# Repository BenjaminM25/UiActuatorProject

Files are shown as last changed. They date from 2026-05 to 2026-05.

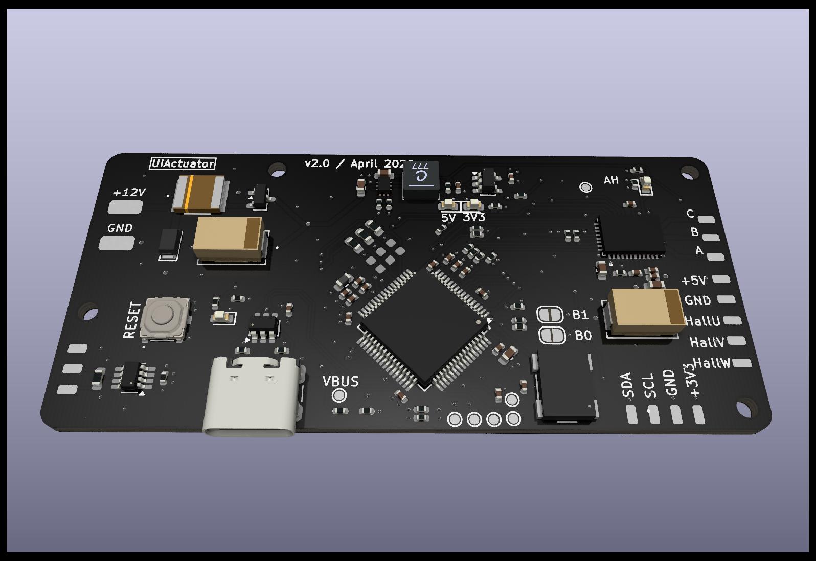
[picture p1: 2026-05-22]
KiCad/PCB_Layout/PCB_raytr.jpg

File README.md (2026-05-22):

# Closed-Loop Linear Actuator

> Bachelor project, University of Agder (UiA), 2026
> Custom BLDC motor controller for a leadscrew linear actuator with
> closed-loop position control.

## Overview

This project contains code and production files for a small linear
actuator using the lead screw principle with a custom pcb. The system
consists of a 12 mm BLDC motor with a 1:24 gearbox, integrated hall-
sensors for motor commutation, a AS5600L magnetic encoder module for
position/velocity control. It also supports communication over CAN
and USB-C.

A demonstration video of the actuator can be found here:

[Demonstration video](https://youtube.com/watch?v=XubzCKECgCM)

## Features

- Trapezoidal 3-PWM/6-PWM commutation (Hall-sensor based)
- Closed-loop position control (profiled trajectory + PID)
- Phase current sensing via ADC
- On-chip temperature monitoring with thermal protection
- CAN (FDCAN) communication
- Live telemetry over USB CDC (Teleplotter)

## Hardware

| Component | Part |
|---|---|
| MCU | STM32G473RC |
| Gate driver | DRV8316 (SPI) |
| Position encoder | AS5600L (I2C) |
| Commutation | Hall sensors |
| CAN transceiver  | TCAN3403 |
| Motor | 12 mm BLDC, 1:24 |

## Third Party

The DRV8316 BLDC Driver has been adapted from the[SIMPLEFOC](https://github.com/simplefoc/Arduino-FOC-drivers/tree/master/src/drivers/drv8316) GitHub library.

## Building & flashing

The CubeIDE project contains custom files for the actuator
within Core/Actuator. The DRV8316 driver, hall encoder and
magnetic encoder is found in Drivers/DRV8316.

The .elf file generated in Debug after building the project
is uploaded to the pcb using STM32CubeProgrammer. First time use
of the pcb requires either a ST-Link debugger using swd or
programming USB-C by setting the mcu in the
DFU(device firmware upgrade) mode.

## Disclaimer

Portions of this firmware were developed with the assistance of
AI-generated code. All such content has been reviewed, tested, and
adapted by the author.

## License
This project is licensed under the MIT License — see the [LICENSE](LICENSE) file.

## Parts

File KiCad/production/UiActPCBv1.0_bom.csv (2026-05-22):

Designator | Footprint | Quantity | Value | LCSC Part #
C1, C14, C15, C22, C24 | C_0402 | 5 | 1uF | C14445
C10, C8, C9 | C_0402 | 3 | 30pF | C107004
C11, C13 | 0603 | 2 | 22uF | C29519229
C12 | 0603 | 1 | 10uF | C96446
C16 | 0603 | 1 | 10uF | C19702
C17, C18, C19, C20, C21, C23, C25, C26 | C_0402 | 8 | 0.1uF | C71687
C2 | 0603 | 1 | 10 uF | C96446
C27 | CAP_EEF_CX_PAN | 1 | EEF-CX0D221R | C165968
C3 | C_0402 | 1 | 0.1 uF | C56392
C31, C32, C33 | C_0402 | 3 | 100nF | C71687
C4 | C_0402 | 1 | 1 uF | C52923
C5, C7 | C_0402 | 2 | 0.1 uF | C71687
C6 | C_0402 | 1 | 47 nF | C285062
D1, D2, D4 | 0603 | 3 | green | C12624
D3 | 0603 | 1 | red | C2286
D5 | VS12VBA1HST15R | 1 | VS12VBA1HST15R | C3711499
F1 | FUSE_SMDF050-2 | 1 | Fuse | C135370
FB1 | L_0603 | 1 | 330R | C113010
J21 | USB_C_Receptacle_GCT_USB4105-xx-A_16P_TopMnt_Horizontal | 1 | USB_C_Receptacle_USB2.0_14P | C2927038
L1 | L_Coilcraft_XxL4020 | 1 | 1u | C5357696
Q1 | SOT-23 | 1 | NCE3407 | C113770
R1, R28, R29 | R_0402 | 3 | 5.1k | C25905
R10, R7, R9 | R_0402 | 3 | 100k | C25530
R11 | R_0402 | 1 | 200k | C25764
R12 | R_0402 | 1 | 470 | C25117
R13, R16 | R_0402 | 2 | 100 | C25076
R14 | R_0402 | 1 | 76.8k | C26987
R15 | R_0402 | 1 | 520 | C25123
R17, R18, R19, R20 | R_0402 | 4 | 10k | C60489
R2, R3, R4 | R_0402 | 3 | 1000 Ohm | C11702
R24 | R_0603 | 1 | 120 | C25079
R25, R26 | R_0402 | 2 | 40k | C25783
R27 | R_0402 | 1 | 33k | C25779
R30 | R_0402 | 1 | 82k | C4142
R5 | R_0402 | 1 | 22 | C25092
R6, R8 | R_0402 | 2 | 10k | C25531
S1 | EVQPLHA15_pushbutton | 1 | EVQ-PLHA15 | C79172
U1 | RGF0040E-IPC_A | 1 | DRV8316RQRGFRQ1 | C5218859
U2 | TPS62903RPJRRPJ0009A | 1 | TPS62903RPJR | C2866502
U3 | SOT-23-5 | 1 | AP2112K-3.3 | C51118
U4 | LQFP-64_10x10mm_P0.5mm | 1 | STM32G473RCTx | C529361
U5 | SOT-23-8_Handsoldering | 1 | TCAN3403 | C35926232
U6 | SOT-23-6 | 1 | USBLC6-2SC6 | C7519
Y1 | X1G004481009712_EPS | 1 | SG-7050CAN | C70513

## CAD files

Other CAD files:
CAD_files/Actuator/Enclosure_assembly.SLDASM
CAD_files/Actuator/SquareTube_bushing.SLDASM
CAD_files/Actuator/AluminiumPipe_magnetball.SLDASM
CAD_files/Actuator/Gear_motor_assembly.SLDASM
CAD_files/Actuator/Motor_with_components.SLDASM
CAD_files/Actuator/Actuator_assembly.SLDASM
KiCad/3D_models/S3B-XH-SM4-TB-LF--SN---3DModel-STEP-56544.STEP
KiCad/Custom_ESC.step
CAD_files/Actuator/AluminiumPipe.SLDPRT
KiCad/3D_models/X1G004481009712_EPS.step
CAD_files/Actuator/MagnetEncoder.SLDPRT
KiCad/3D_models/GX_SX_CX_HX.stp
CAD_files/Actuator/M2HeatInsert.SLDPRT
KiCad/3D_models/XFL4020-102MEC.stp
KiCad/3D_models/SMASeries_LTF.step
KiCad/3D_models/TYPE-C-31-M-12--3DModel-STEP-56544.STEP
CAD_files/Actuator/Enclosure.SLDPRT
CAD_files/Actuator/M2_PanHead.SLDPRT
CAD_files/Actuator/BLDC_motor.SLDPRT
CAD_files/Actuator/BallBearing.SLDPRT
CAD_files/Actuator/Enclosure_PCB.SLDPRT
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

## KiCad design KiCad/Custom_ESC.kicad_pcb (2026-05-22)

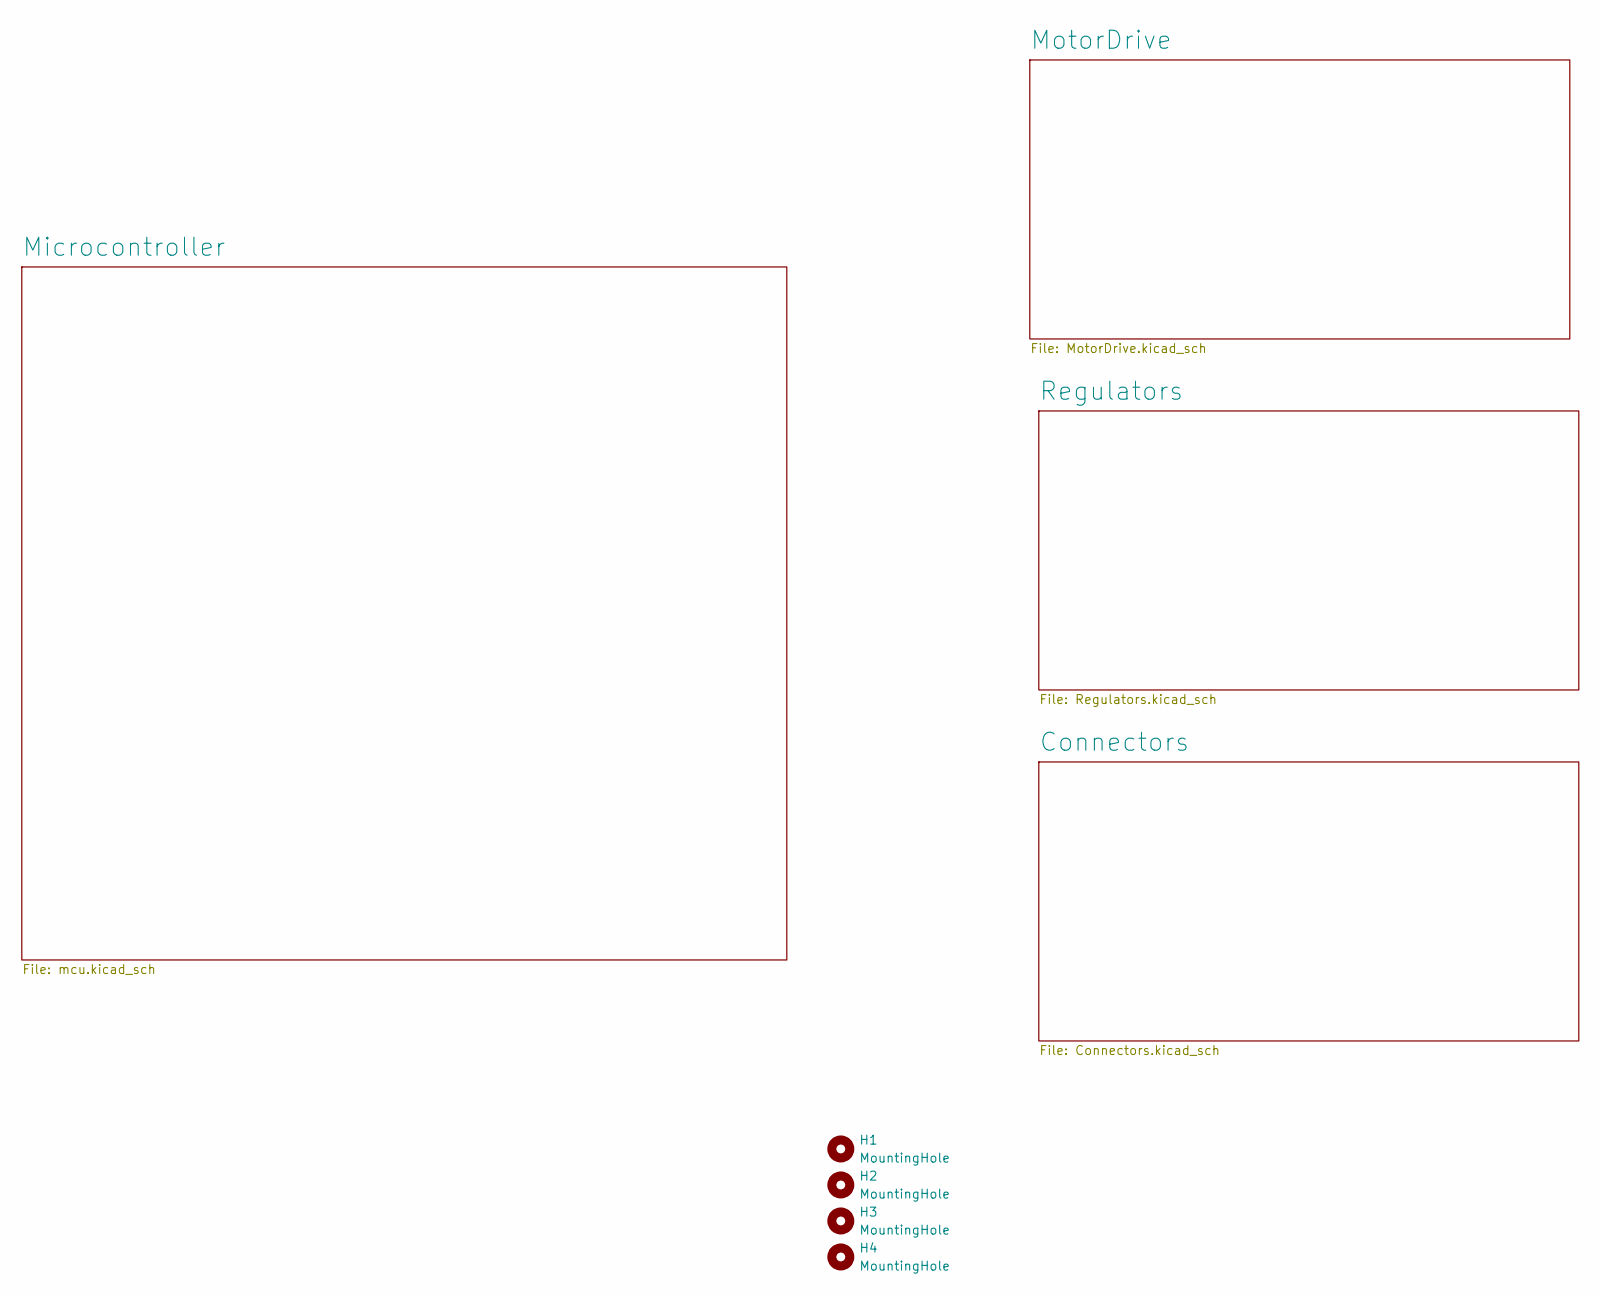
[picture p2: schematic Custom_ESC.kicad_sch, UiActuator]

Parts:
H1, H2, H3, H4: MountingHole; MountingHole_2.2mm_M2

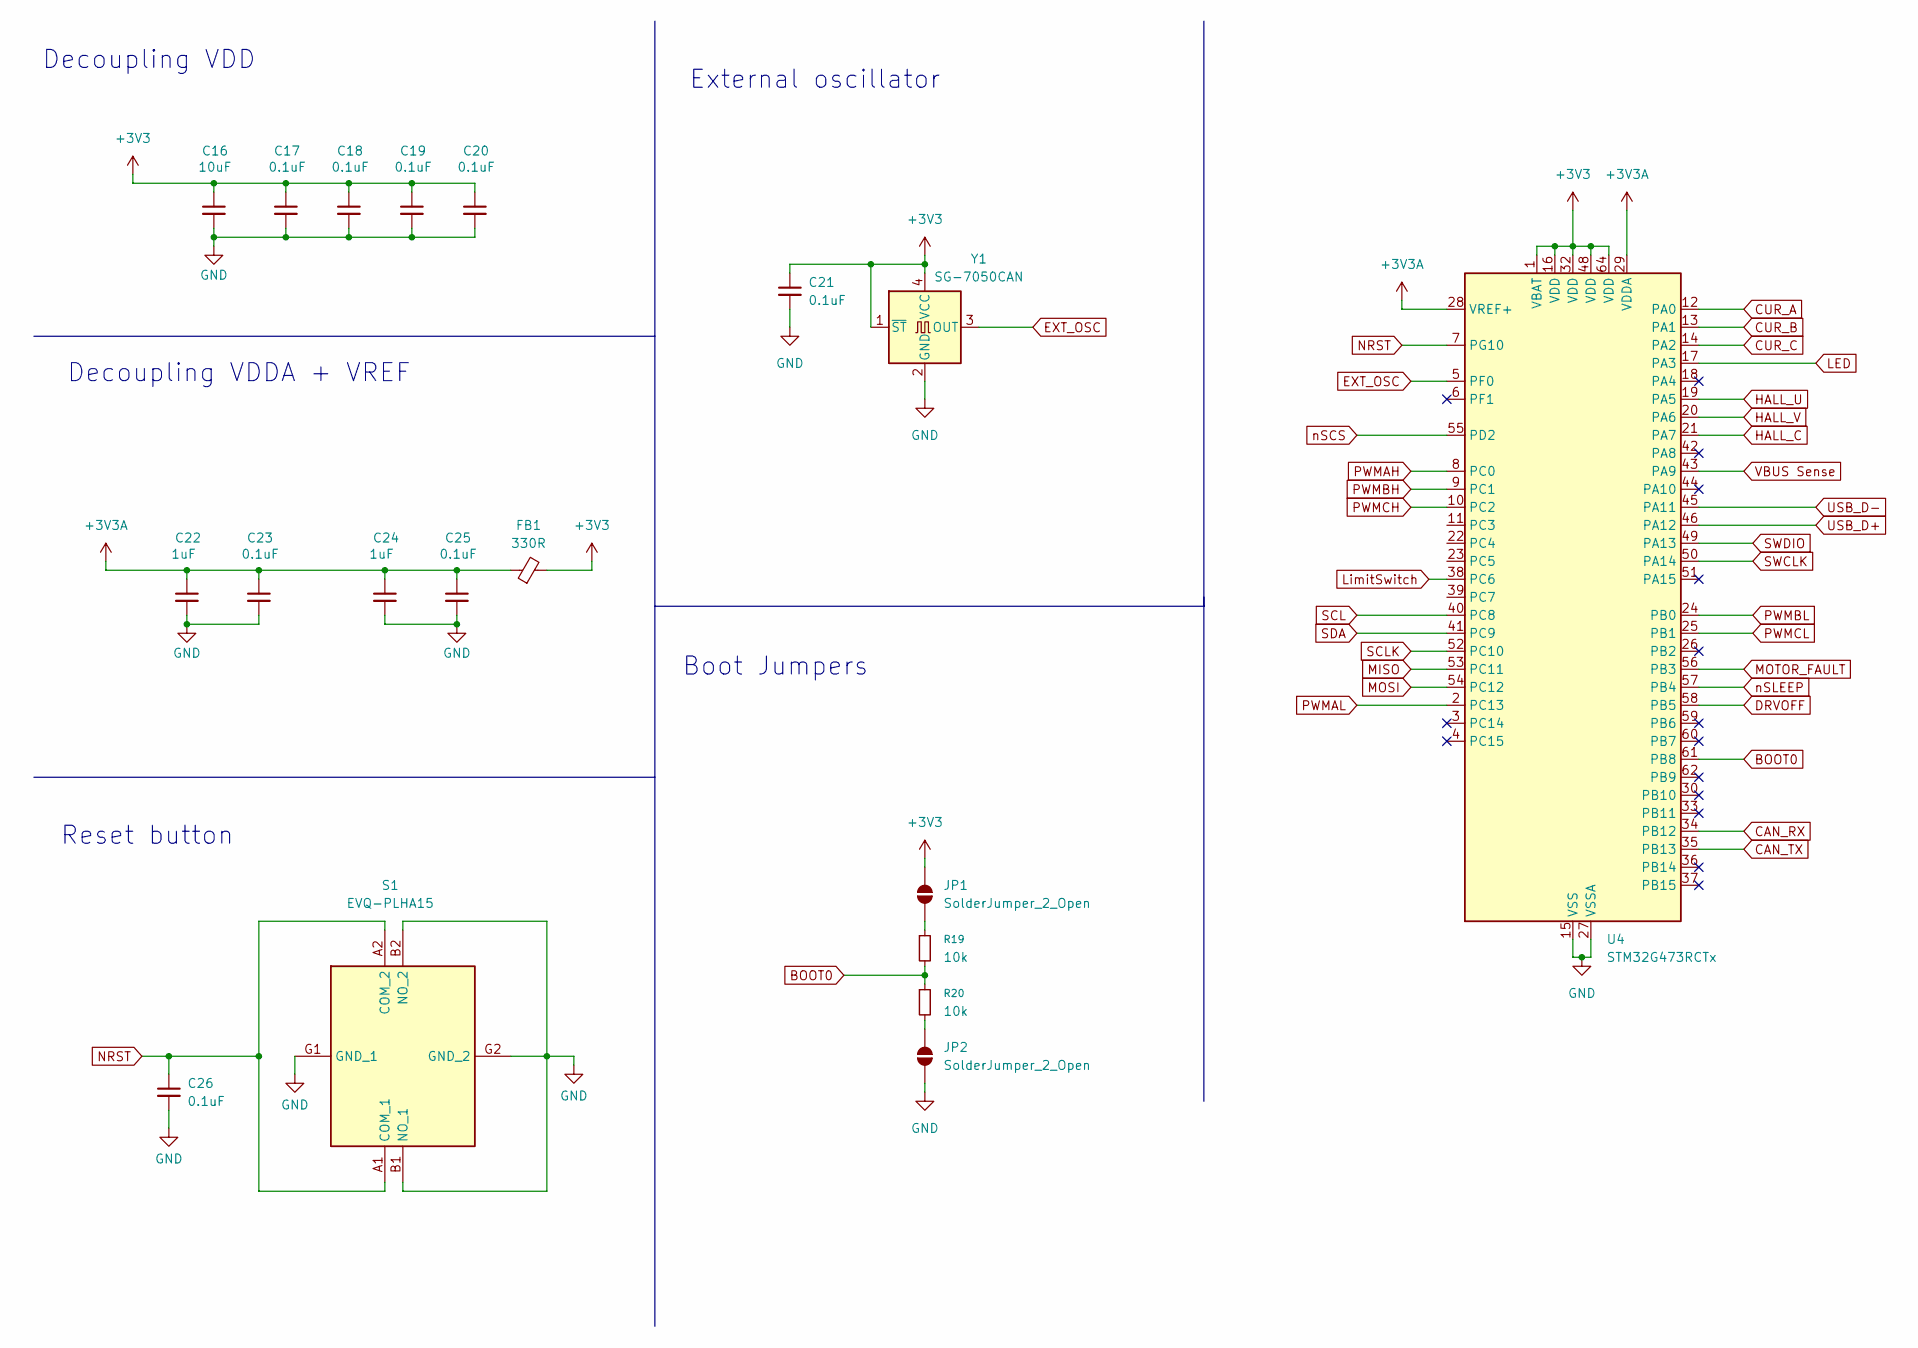
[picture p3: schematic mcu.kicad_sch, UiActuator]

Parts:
C16: 10uF; C_0603_1608Metric; LCSC C19702
C17, C18, C19, C20, C21, C23, C25, C26: 0.1uF; C_0402; LCSC C71687
C22, C24: 1uF; C_0402; LCSC C14445
FB1: 330R; L_0603; LCSC C113010
JP1, JP2: SolderJumper_2_Open; SolderJumper-2_P1.3mm_Open_RoundedPad1.0x1.5mm
R19, R20: 10k; R_0402; LCSC C60489
S1: EVQ-PLHA15; EVQPLHA15_pushbutton; Mouser Part Number 667-EVQ-PLHA15
U4: STM32G473RCTx; LQFP-64_10x10mm_P0.5mm; LCSC C529361
Y1: SG-7050CAN; X1G004481009712_EPS; LCSC C70513

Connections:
+3V3: C16.1, C17.1, C18.1, C19.1, C20.1, C21.1, FB1.2, JP1.2 (B), U4.1 (VBAT), U4.16 (VDD), U4.32 (VDD), U4.48 (VDD), U4.64 (VDD), Y1.1 (~ST), Y1.4 (VCC); also elsewhere on the board
+3V3A: C22.1, C23.1, C24.1, C25.1, FB1.1, U4.28 (VREF+), U4.29 (VDDA); also elsewhere on the board
BOOT0: R19.2, R20.1, U4.61 (PB8)
CAN_RX: U4.34 (PB12); also elsewhere on the board
CAN_TX: U4.35 (PB13); also elsewhere on the board
CUR_A: U4.12 (PA0); also elsewhere on the board
CUR_B: U4.13 (PA1); also elsewhere on the board
CUR_C: U4.14 (PA2); also elsewhere on the board
DRVOFF: U4.58 (PB5); also elsewhere on the board
EXT_OSC: U4.5 (PF0), Y1.3 (OUT)
GND: C16.2, C17.2, C18.2, C19.2, C20.2, C21.2, C22.2, C23.2, C24.2, C25.2, C26.2, JP2.1 (A), S1.B1 (NO_1), S1.B2 (NO_2), S1.G1 (GND_1), S1.G2 (GND_2), U4.15 (VSS), U4.27 (VSSA), U4.31 (VSS), U4.47 (VSS), U4.63 (VSS), Y1.2 (GND); also elsewhere on the board
HALL_C: U4.21 (PA7); also elsewhere on the board
HALL_U: U4.19 (PA5); also elsewhere on the board
HALL_V: U4.20 (PA6); also elsewhere on the board
LED: U4.17 (PA3); also elsewhere on the board
LimitSwitch: U4.38 (PC6); also elsewhere on the board
MISO: U4.53 (PC11); also elsewhere on the board
MOSI: U4.54 (PC12); also elsewhere on the board
MOTOR_FAULT: U4.56 (PB3); also elsewhere on the board
NRST: C26.1, S1.A1 (COM_1), S1.A2 (COM_2), U4.7 (PG10); also elsewhere on the board
unnamed: JP1.1 (A), R19.1
unnamed: JP2.2 (B), R20.2
PWMAH: U4.8 (PC0); also elsewhere on the board
PWMAL: U4.2 (PC13); also elsewhere on the board
PWMBH: U4.9 (PC1); also elsewhere on the board
PWMBL: U4.24 (PB0); also elsewhere on the board
PWMCH: U4.10 (PC2); also elsewhere on the board
PWMCL: U4.25 (PB1); also elsewhere on the board
SCL: U4.40 (PC8); also elsewhere on the board
SCLK: U4.52 (PC10); also elsewhere on the board
SDA: U4.41 (PC9); also elsewhere on the board
SWCLK: U4.50 (PA14); also elsewhere on the board
SWDIO: U4.49 (PA13); also elsewhere on the board
USB_D+: U4.46 (PA12); also elsewhere on the board
USB_D-: U4.45 (PA11); also elsewhere on the board
VBUS Sense: U4.43 (PA9); also elsewhere on the board
nSCS: U4.55 (PD2); also elsewhere on the board
nSLEEP: U4.57 (PB4); also elsewhere on the board

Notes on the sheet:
External oscillator
Decoupling VDD
Reset button
Boot Jumpers
Decoupling VDDA + VREF

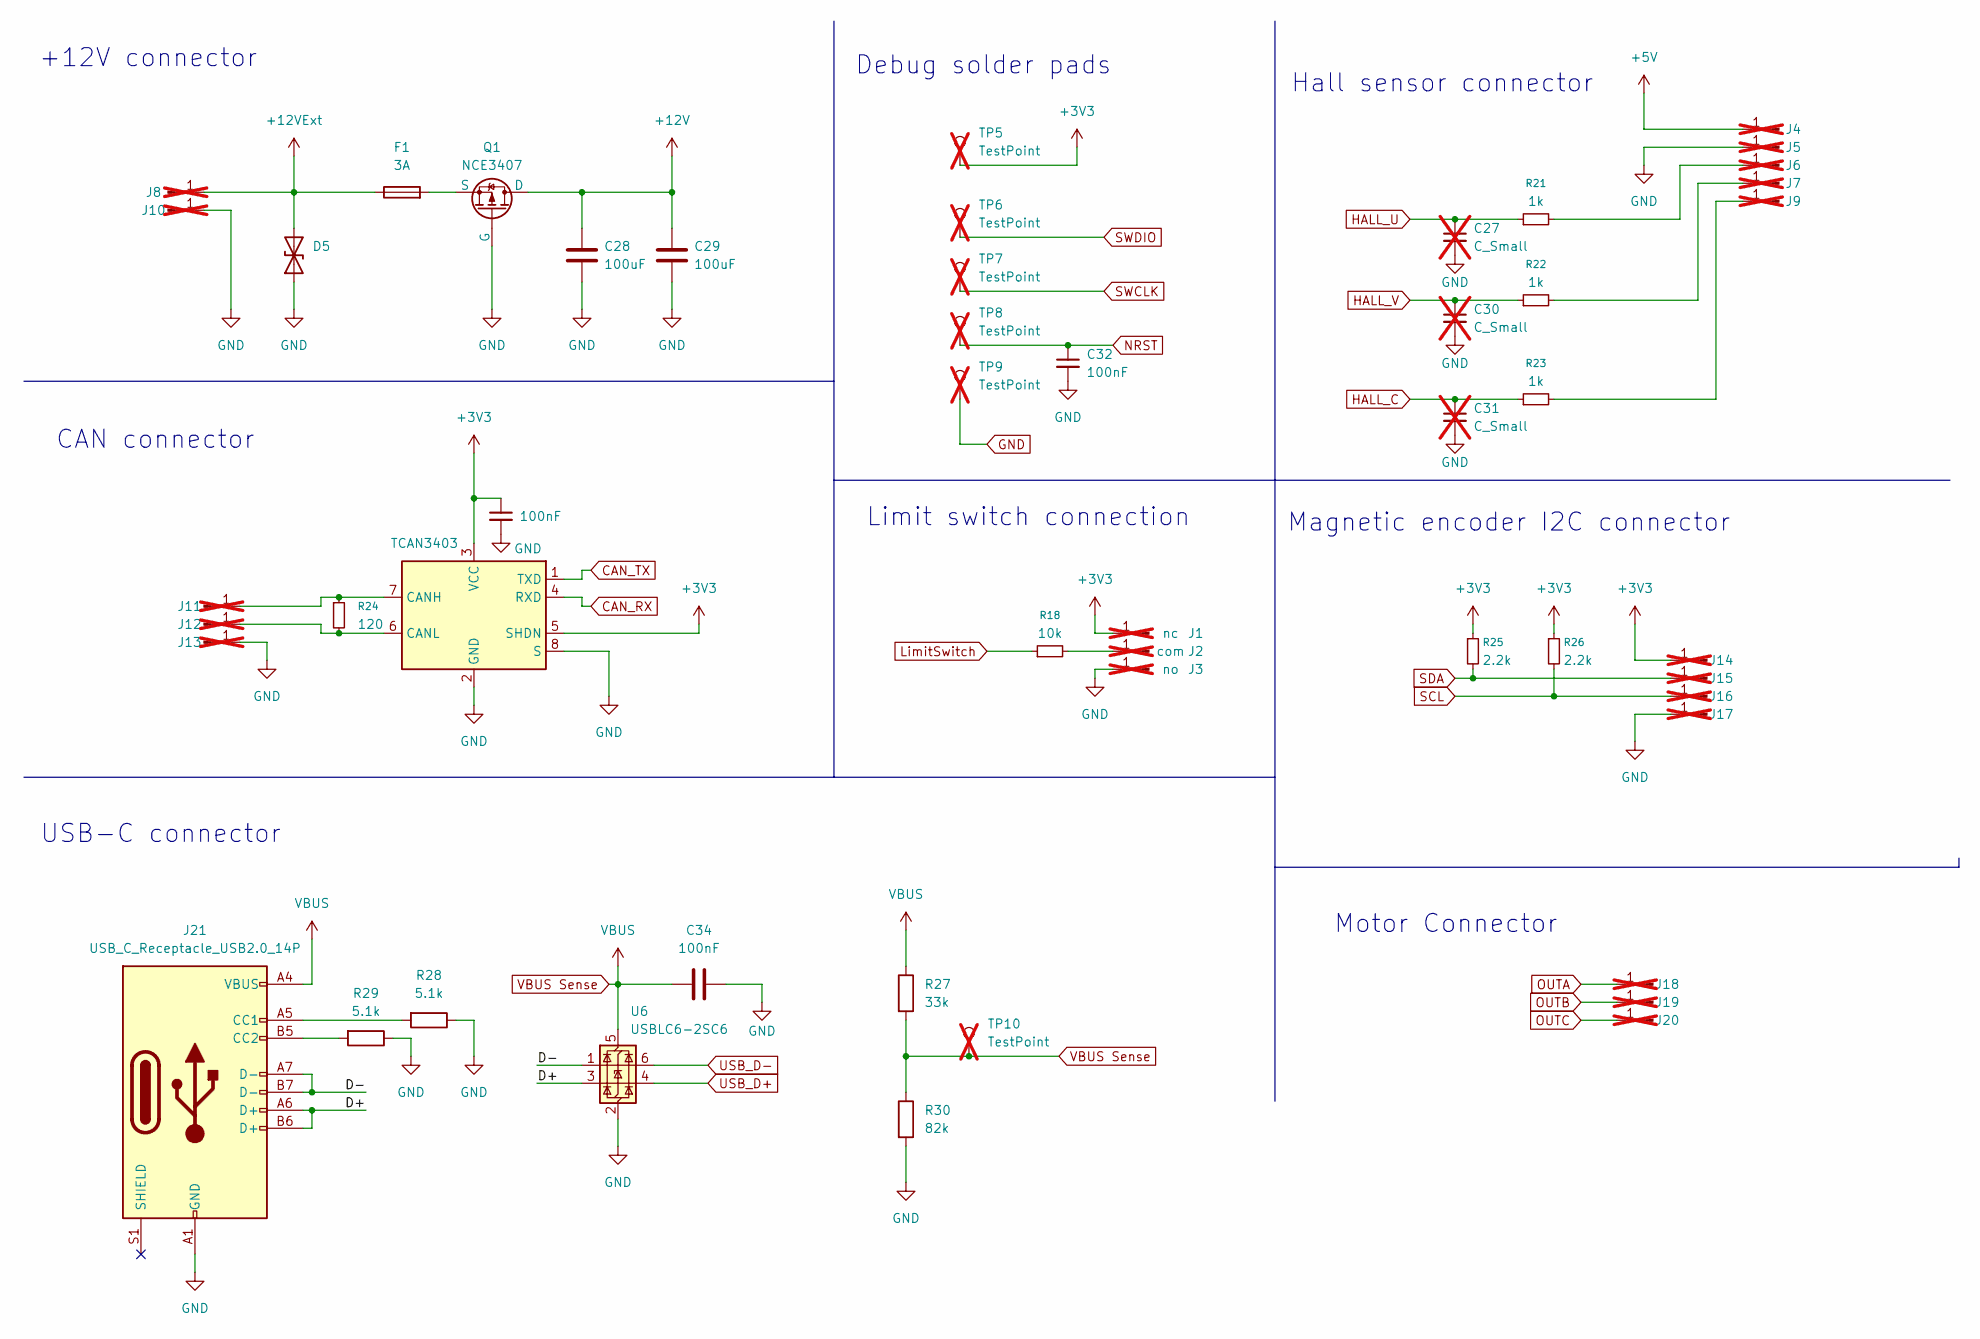
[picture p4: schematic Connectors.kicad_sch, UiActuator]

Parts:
C27, C30, C31: C_Small; C_0603; not fitted
C28, C29: 100uF; CAP_T55D_VIS; LCSC C215892
C32, C33, C34: 100nF; C_0402; LCSC C71687
D5: 13; D_SOD-123FL; LCSC C5353308
F1: 3A; FUSE_SMDF050-2; LCSC C135370
J1: nc; TestPoint_Pad_D1.0mm; not fitted
J2: com; TestPoint_Pad_D1.0mm; not fitted
J3: no; TestPoint_Pad_D1.0mm; not fitted
J4, J5, J6, J7, J9, J11, J12, J13, J14, J15, J16, J17, J18, J19, J20: A; SolderWirePad_1x01_SMD_1x2mm; not fitted
J8, J10: A; SolderWirePad_1x01_SMD_2x4mm; not fitted
J21: USB_C_Receptacle_USB2.0_14P; USB_C_Receptacle_GCT_USB4105-xx-A_16P_TopMnt_Horizontal; LCSC C2927038
Q1: NCE3407; SOT-23; LCSC C113770
R18: 10k; R_0402; LCSC C60489
R21, R22, R23: 1k; C_0603; LCSC C21190
R24: 120; R_0603; LCSC C22787
R25, R26: 2.2k; R_0402; LCSC C25879
R27: 33k; R_0402; LCSC C25779
R28, R29: 5.1k; R_0402; LCSC C25905
R30: 82k; R_0402; LCSC C4142
TP5, TP6, TP7, TP8, TP9, TP10: TestPoint; TestPoint_Pad_D1.0mm; not fitted
U5: TCAN3403; SOT-23-8_Handsoldering; LCSC C35926232
U6: USBLC6-2SC6; SOT-23-6; LCSC C7519

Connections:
+3V3: C33.1, J1.1, J14.1, R25.1, R26.1, TP5.1, U5.3 (VCC), U5.5 (SHDN); also elsewhere on the board
+5V: J4.1; also elsewhere on the board
+12V: C28.1, C29.1, Q1.3 (D); also elsewhere on the board
+12VExt: D5.2 (A2), F1.1, J8.1
/Connectors/D+: J21.A6 (D+), J21.B6 (D+), U6.3 (I/O2)
/Connectors/D-: J21.A7 (D-), J21.B7 (D-), U6.1 (I/O1)
CAN_RX: U5.4 (RXD); also elsewhere on the board
CAN_TX: U5.1 (TXD); also elsewhere on the board
GND: C27.2, C28.2, C29.2, C30.2, C31.2, C32.2, C33.2, C34.1, D5.1 (A1), J3.1, J5.1, J10.1, J13.1, J17.1, J21.A1 (GND), J21.A12 (GND), J21.B1 (GND), J21.B12 (GND), Q1.1 (G), R28.1, R29.1, R30.2, TP9.1, U5.2 (GND), U5.8 (S), U6.2 (GND); also elsewhere on the board
HALL_C: C31.1, R23.1; also elsewhere on the board
HALL_U: C27.1, R21.1; also elsewhere on the board
HALL_V: C30.1, R22.1; also elsewhere on the board
LimitSwitch: R18.1; also elsewhere on the board
NRST: C32.1, TP8.1; also elsewhere on the board
unnamed: J2.1, R18.2
unnamed: J6.1, R21.2
unnamed: J7.1, R22.2
unnamed: J9.1, R23.2
unnamed: J11.1, R24.1, U5.7 (CANH)
unnamed: J12.1, R24.2, U5.6 (CANL)
unnamed: J21.A5 (CC1), R28.2
unnamed: J21.B5 (CC2), R29.2
unnamed: F1.2, Q1.2 (S)
OUTA: J18.1; also elsewhere on the board
OUTB: J19.1; also elsewhere on the board
OUTC: J20.1; also elsewhere on the board
SCL: J16.1, R26.2; also elsewhere on the board
SDA: J15.1, R25.2; also elsewhere on the board
SWCLK: TP7.1; also elsewhere on the board
SWDIO: TP6.1; also elsewhere on the board
USB_D+: U6.4 (I/O2); also elsewhere on the board
USB_D-: U6.6 (I/O1); also elsewhere on the board
VBUS Sense: C34.2, J21.A4 (VBUS), J21.A9 (VBUS), J21.B4 (VBUS), J21.B9 (VBUS), R27.1, R27.2, R30.1, TP10.1, U6.5 (VBUS); also elsewhere on the board

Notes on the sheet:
USB-C connector
Hall sensor connector
CAN connector
Magnetic encoder I2C connector
Motor Connector
+12V connector
Limit switch connection
Debug solder pads

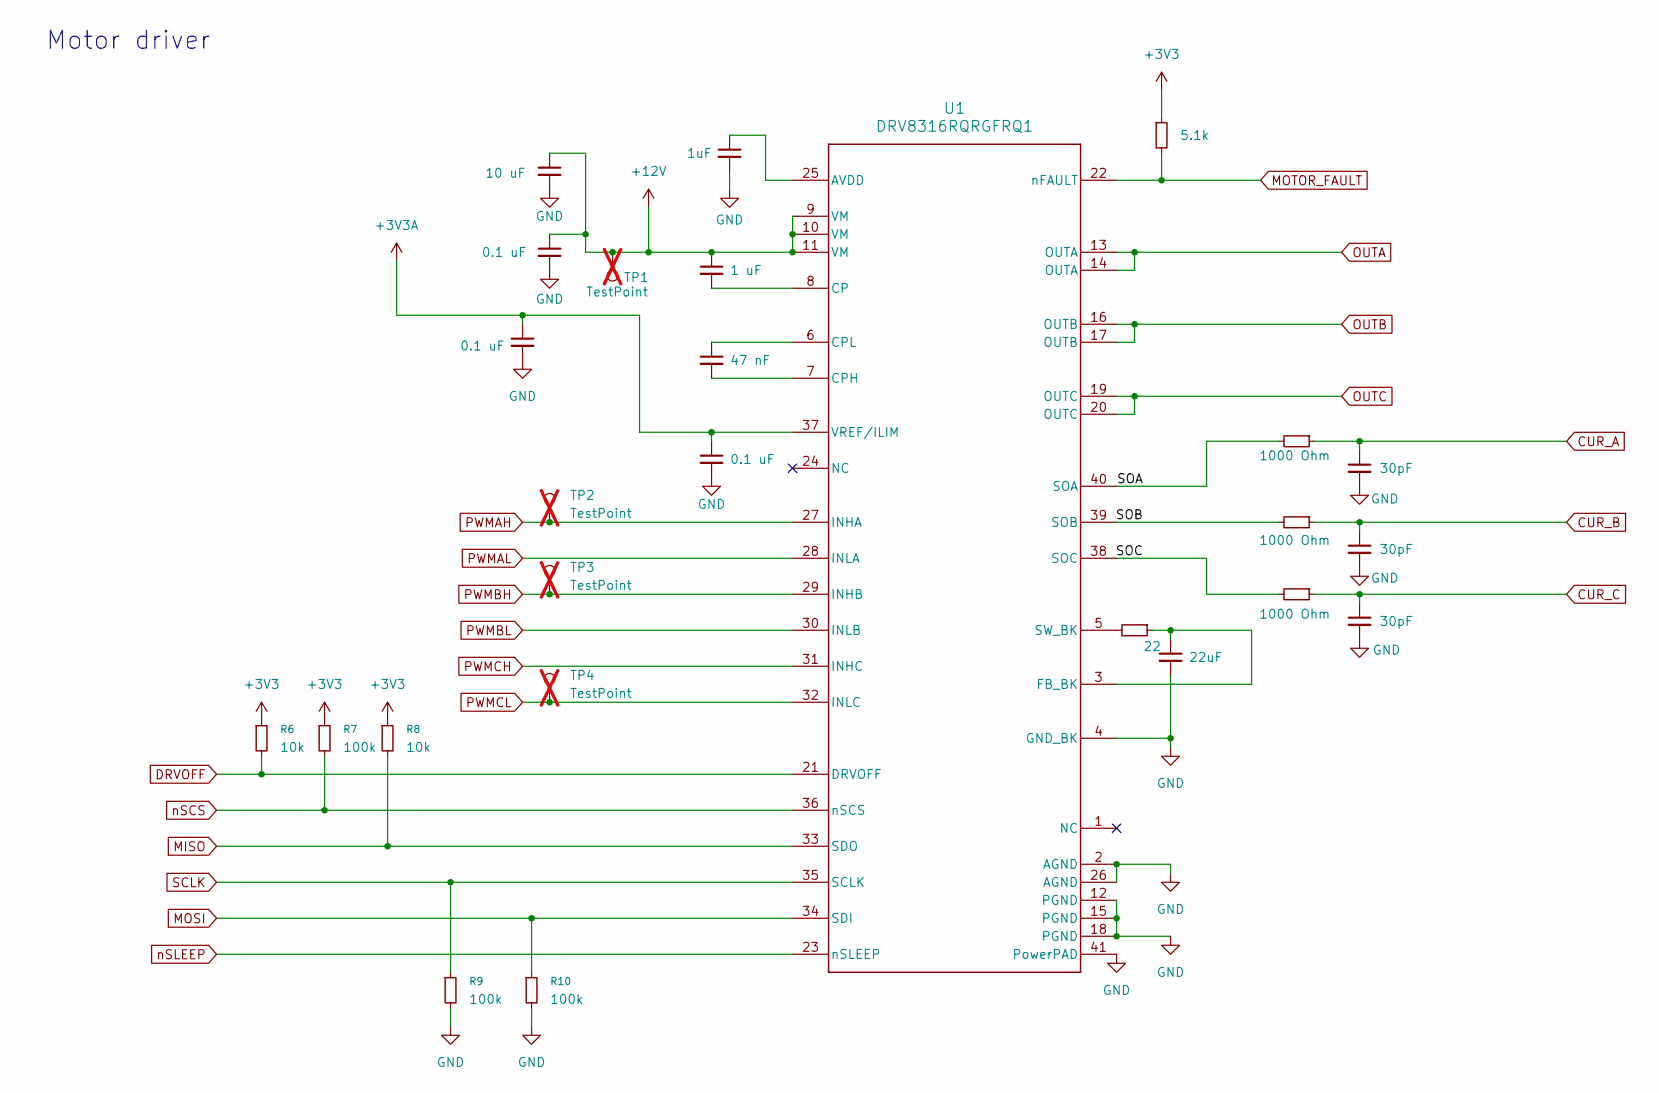
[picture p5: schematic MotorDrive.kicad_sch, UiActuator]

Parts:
C1: 1uF; C_0402; LCSC C14445
C2: 10 uF; C_0603_1608Metric; LCSC C96446
C3: 0.1 uF; C_0402; LCSC C56392
C4: 1 uF; C_0402; LCSC C52923
C5, C7: 0.1 uF; C_0402; LCSC C71687
C6: 47 nF; C_0402; LCSC C285062
C8, C9, C10: 30pF; C_0402; LCSC C107004
C11: 22uF; C_0603_1608Metric; LCSC C29519229
R1: 5.1k; R_0402; LCSC C25905
R2, R3, R4: 1000 Ohm; R_0402; LCSC C11702
R5: 22; R_0402; LCSC C25092
R6, R8: 10k; R_0402; LCSC C25531
R7, R9, R10: 100k; R_0402; LCSC C25530
TP1, TP2, TP3, TP4: TestPoint; TestPoint_Pad_D1.0mm; not fitted
U1: DRV8316RQRGFRQ1; RGF0040E-IPC_A; LCSC C5218859

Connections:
+3V3: R1.1, R6.1, R7.1, R8.1; also elsewhere on the board
+3V3A: C5.1, C7.1, U1.37 (VREF/ILIM); also elsewhere on the board
+12V: C2.1, C3.1, C4.1, TP1.1, U1.9 (VM), U1.10 (VM), U1.11 (VM); also elsewhere on the board
/MotorDrive/SOA: R2.2, U1.40 (SOA)
/MotorDrive/SOB: R3.2, U1.39 (SOB)
/MotorDrive/SOC: R4.2, U1.38 (SOC)
CUR_A: C8.1, R2.1; also elsewhere on the board
CUR_B: C9.1, R3.1; also elsewhere on the board
CUR_C: C10.1, R4.1; also elsewhere on the board
DRVOFF: R6.2, U1.21 (DRVOFF); also elsewhere on the board
GND: C1.2, C2.2, C3.2, C5.2, C7.2, C8.2, C9.2, C10.2, C11.2, R9.2, R10.2, U1.2 (AGND), U1.4 (GND_BK), U1.12 (PGND), U1.15 (PGND), U1.18 (PGND), U1.26 (AGND), U1.41 (PowerPAD); also elsewhere on the board
MISO: R8.2, U1.33 (SDO); also elsewhere on the board
MOSI: R10.1, U1.34 (SDI); also elsewhere on the board
MOTOR_FAULT: R1.2, U1.22 (nFAULT); also elsewhere on the board
unnamed: C1.1, U1.25 (AVDD)
unnamed: C4.2, U1.8 (CP)
unnamed: C6.2, U1.7 (CPH)
unnamed: C6.1, U1.6 (CPL)
unnamed: C11.1, R5.1, U1.3 (FB_BK)
unnamed: R5.2, U1.5 (SW_BK)
OUTA: U1.13 (OUTA), U1.14 (OUTA); also elsewhere on the board
OUTB: U1.16 (OUTB), U1.17 (OUTB); also elsewhere on the board
OUTC: U1.19 (OUTC), U1.20 (OUTC); also elsewhere on the board
PWMAH: TP2.1, U1.27 (INHA); also elsewhere on the board
PWMAL: U1.28 (INLA); also elsewhere on the board
PWMBH: TP3.1, U1.29 (INHB); also elsewhere on the board
PWMBL: U1.30 (INLB); also elsewhere on the board
PWMCH: U1.31 (INHC); also elsewhere on the board
PWMCL: TP4.1, U1.32 (INLC); also elsewhere on the board
SCLK: R9.1, U1.35 (SCLK); also elsewhere on the board
nSCS: R7.2, U1.36 (nSCS); also elsewhere on the board
nSLEEP: U1.23 (nSLEEP); also elsewhere on the board

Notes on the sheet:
Motor driver

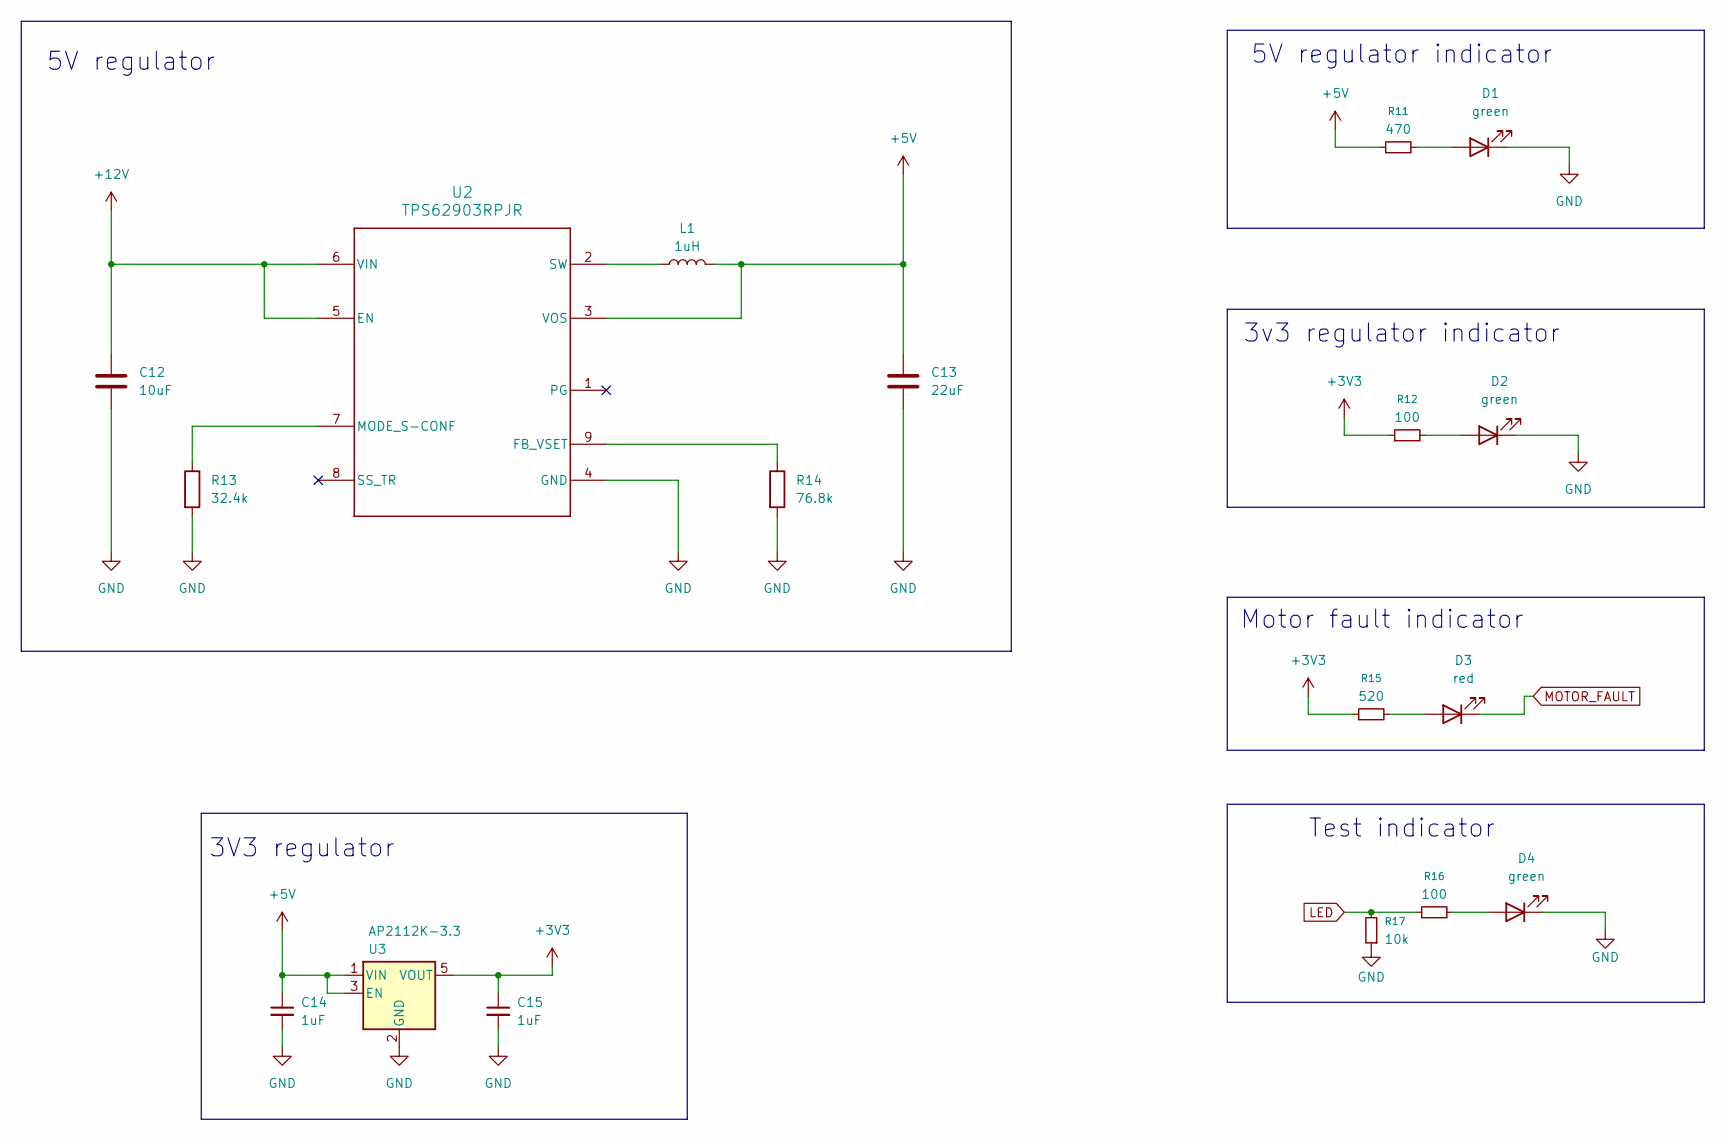
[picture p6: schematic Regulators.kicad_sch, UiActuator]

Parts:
C12: 10uF; C_0603_1608Metric; LCSC C96446
C13: 22uF; C_0603_1608Metric; LCSC C29519229
C14, C15: 1uF; C_0402; LCSC C14445
D1, D2, D4: green; LED_0603_1608Metric; LCSC C12624
D3: red; LED_0603_1608Metric; LCSC C2286
L1: 1uH; L_Coilcraft_XxL4020; LCSC C5357696
R11: 470; R_0402; LCSC C25117
R12, R16: 100; R_0402; LCSC C25076
R13: 32.4k; R_0402; LCSC C26974
R14: 76.8k; R_0402; LCSC C26987
R15: 520; R_0402; LCSC C25123
R17: 10k; R_0402; LCSC C60489
U2: TPS62903RPJR; TPS62903RPJRRPJ0009A; LCSC C2866502
U3: AP2112K-3.3; SOT-23-5; LCSC C51118

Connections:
+3V3: C15.1, R12.1, R15.1, U3.5 (VOUT); also elsewhere on the board
+5V: C13.1, C14.1, L1.2, R11.1, U2.3 (VOS), U3.1 (VIN), U3.3 (EN); also elsewhere on the board
+12V: C12.1, U2.5 (EN), U2.6 (VIN); also elsewhere on the board
GND: C12.2, C13.2, C14.2, C15.2, D1.1 (K), D2.1 (K), D4.1 (K), R13.2, R14.2, R17.1, U2.4 (GND), U3.2 (GND); also elsewhere on the board
LED: R16.1, R17.2; also elsewhere on the board
MOTOR_FAULT: D3.1 (K); also elsewhere on the board
unnamed: D1.2 (A), R11.2
unnamed: D2.2 (A), R12.2
unnamed: D3.2 (A), R15.2
unnamed: D4.2 (A), R16.2
unnamed: R14.1, U2.9 (FB_VSET)
unnamed: R13.1, U2.7 (MODE_S-CONF)
unnamed: L1.1, U2.2 (SW)

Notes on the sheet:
3v3 regulator indicator
Motor fault indicator
5V regulator
3V3 regulator
Test indicator
5V regulator indicator

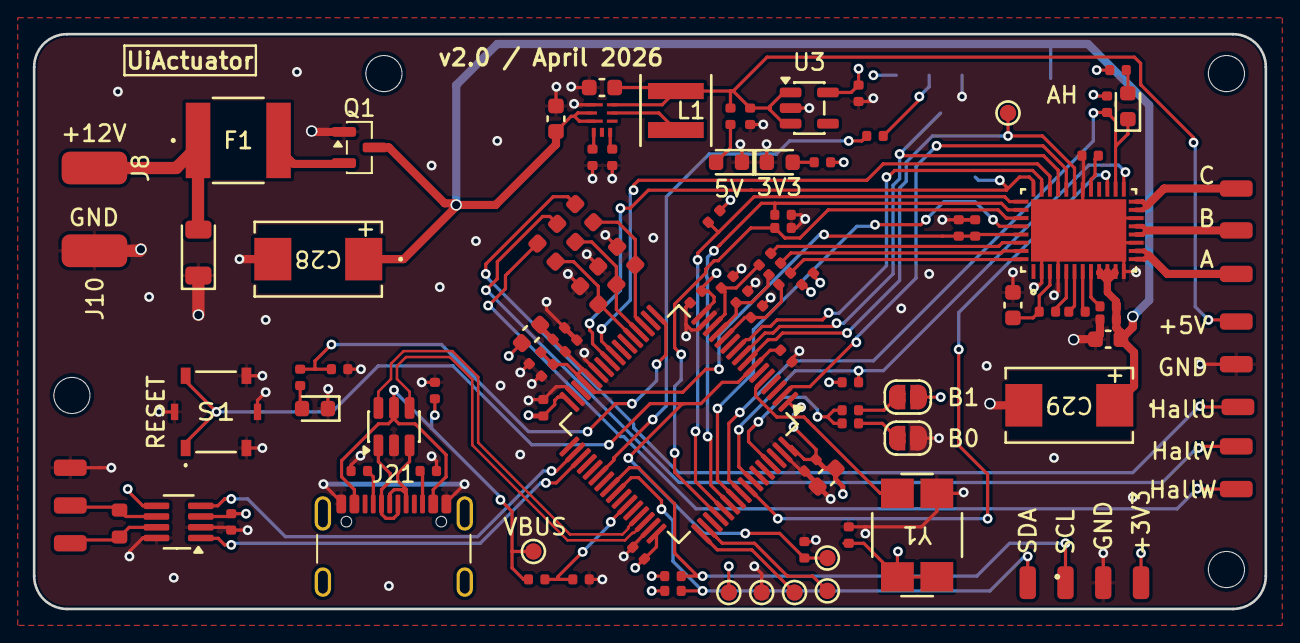
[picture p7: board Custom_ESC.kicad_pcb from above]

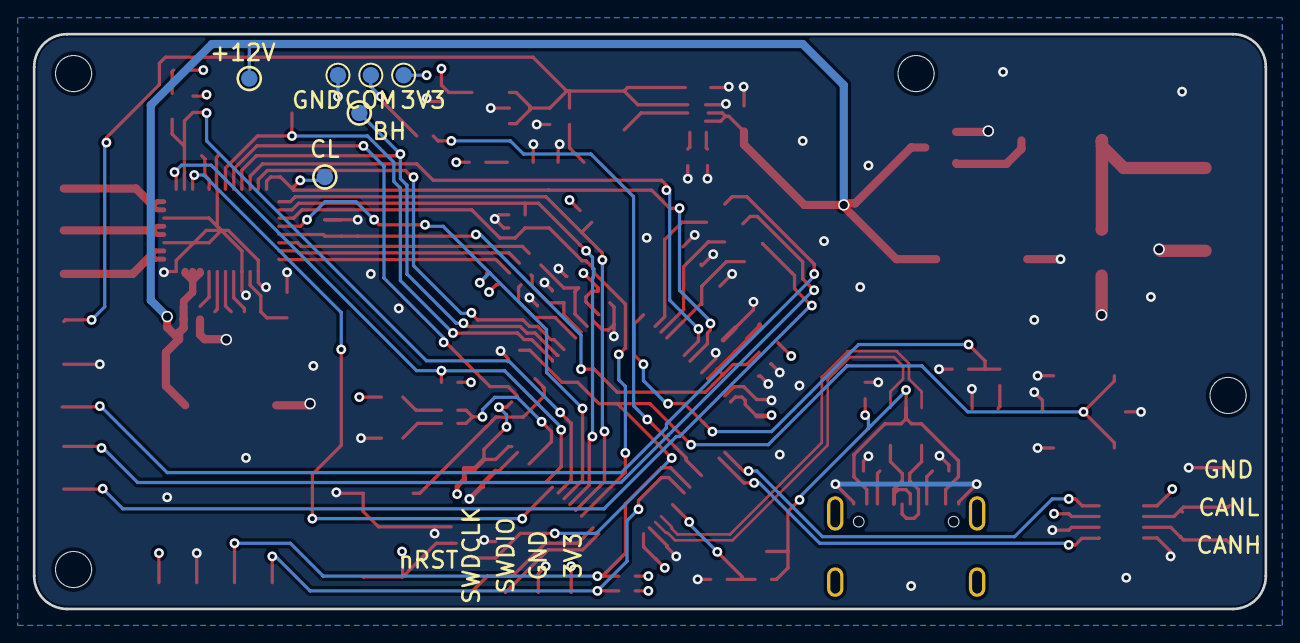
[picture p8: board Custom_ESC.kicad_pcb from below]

Board: 4 copper layers, 75.0 x 35.0 mm, 118 parts (6 on the bottom side), 71 nets.

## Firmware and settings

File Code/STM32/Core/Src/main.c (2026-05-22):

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
/* Includes ------------------------------------------------------------------*/
#include "main.h"
#include "adc.h"
#include "fdcan.h"
#include "i2c.h"
#include "spi.h"
#include "tim.h"
#include "usb_device.h"
#include "gpio.h"

/* USER CODE BEGIN Includes */

#include "bootloader.h"
#include "TestUSB.h"
#include "testcan.h"
#include "testhall.h"
#include "MotorApp.h"
#include "SPITest.h"
#include "Diagnostics.h"
#include "plot.h"
#include "Commcalib.h"
#include "TestADC.h"
#include "TempSensor.h"
#include "TempTest.h"
#include "CANBus.h"

/* USER CODE END Includes */


/* USER CODE BEGIN PV */

  uint32_t last_encoder = 0;
  uint32_t last_usb     = 0;
  uint32_t lastTempRead = 0;
//  uint32_t last_can = 0;
  //uint8_t testDone = 0;
  //uint8_t diagDone = 0;
  //uint8_t spiTestDone = 0;
  //uint8_t calibDone = 0;
  //uint8_t lastPressed = 0;

  extern volatile uint16_t adc_raw[3];
  extern volatile uint32_t adc_cb_count;

/* USER CODE END PV */

void SystemClock_Config(void);
/**
  * @brief  The application entry point.
  * @retval int
  */
int main(void)
{

  /* USER CODE BEGIN 1 */

  checkAndJumpToBootloader();

  /* USER CODE END 1 */

  /* MCU Configuration--------------------------------------------------------*/

  /* Reset of all peripherals, Initializes the Flash interface and the Systick. */
  HAL_Init();

  /* Configure the system clock */
  SystemClock_Config();

  /* Initialize all configured peripherals */
  MX_GPIO_Init();
  MX_USB_Device_Init();
  MX_I2C3_Init();
  MX_FDCAN2_Init();
  MX_TIM2_Init();
  MX_SPI3_Init();
  MX_TIM1_Init();
  MX_ADC1_Init();
  MX_ADC5_Init();
  MX_TIM6_Init();
  /* USER CODE BEGIN 2 */

  HAL_TIM_Base_Start(&htim2);
  HAL_Delay(500);


  MotorApp_Init();
  TestADC_Init();
//  TEMPTEST_Init();

  CANBus_Init();
//  CANBus_EnableAutoEcho(0);   /* optional */

  uint8_t payload[8] = {1,2,3,4,5,6,7,8};


  HAL_Delay(10);

  /* USER CODE END 2 */

  /* Infinite loop */
  /* USER CODE BEGIN WHILE */
  while (1)
  {


	  uint32_t now = HAL_GetTick();

	  if (now - last_usb >= 500)
	  {
		  last_usb = now;
		  TESTUSB_Update();
	  }


//	  CANBus_Update();
//
//	  /* Handle incoming frames */
//	  uint32_t id;
//	  uint8_t  data[8];
//	  uint8_t  len;
//	  while (CANBus_Receive(&id, data, &len))
//	  {
//		  /* do something with id/data/len */
//	  }
//
//	  CANBus_Send(0x123, payload, 8);
//	  HAL_Delay(100);


	  MotorApp_Run();

	  TestADC_Run();
//
//
//	  static uint32_t lastDiag = 0;
//	  if (now - lastDiag >= 1000)
//	  {
//	      lastDiag = now;
//	      Plot_Int("plot_dropped", (int32_t)Plot_DroppedCount());
//	      Plot_Int("plot_queued",  (int32_t)Plot_QueuedBytes());
//	  }
//
//
////	  TEMPTEST_Run();
//
	  static uint32_t lastPlot = 0;
	  if (now - lastPlot >= 10)
	  {
		  lastPlot = now;
		  Plot_Flush();
	  }



    /* USER CODE END WHILE */

    /* USER CODE BEGIN 3 */
  }
  /* USER CODE END 3 */
}

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


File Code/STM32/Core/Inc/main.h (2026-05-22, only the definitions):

#define PWMAL_Pin GPIO_PIN_13
#define PWMAL_GPIO_Port GPIOC
#define PWMAH_Pin GPIO_PIN_0
#define PWMAH_GPIO_Port GPIOC
#define PWMBH_Pin GPIO_PIN_1
#define PWMBH_GPIO_Port GPIOC
#define PWMCH_Pin GPIO_PIN_2
#define PWMCH_GPIO_Port GPIOC
#define LED_Pin GPIO_PIN_3
#define LED_GPIO_Port GPIOA
#define HALL_U_Pin GPIO_PIN_5
#define HALL_U_GPIO_Port GPIOA
#define HALL_U_EXTI_IRQn EXTI9_5_IRQn
#define HALL_V_Pin GPIO_PIN_6
#define HALL_V_GPIO_Port GPIOA
#define HALL_V_EXTI_IRQn EXTI9_5_IRQn
#define HALL_W_Pin GPIO_PIN_7
#define HALL_W_GPIO_Port GPIOA
#define HALL_W_EXTI_IRQn EXTI9_5_IRQn
#define PWMBL_Pin GPIO_PIN_0
#define PWMBL_GPIO_Port GPIOB
#define PWMCL_Pin GPIO_PIN_1
#define PWMCL_GPIO_Port GPIOB
#define LIMIT_SWITCH_Pin GPIO_PIN_6
#define LIMIT_SWITCH_GPIO_Port GPIOC
#define VBUS_Pin GPIO_PIN_9
#define VBUS_GPIO_Port GPIOA
#define DRV8316nSCS_Pin GPIO_PIN_2
#define DRV8316nSCS_GPIO_Port GPIOD
#define nFAULT_Pin GPIO_PIN_3
#define nFAULT_GPIO_Port GPIOB
#define nSLEEP_Pin GPIO_PIN_4
#define nSLEEP_GPIO_Port GPIOB
#define DRVOFF_Pin GPIO_PIN_5
#define DRVOFF_GPIO_Port GPIOB

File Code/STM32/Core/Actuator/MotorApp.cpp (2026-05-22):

#include "MotorApp.h"
#include "BLDCDriver3PWM.h"
#include "BLDCDriver6PWM.h"
#include "BLDCMotor.h"
#include "plot.h"
#include "main.h"
#include "tim.h"
#include "spi.h"
#include "HallSensor.h"
#include "usbd_cdc_if.h"
#include "LimitSwitch.h"
#include <stdlib.h>   /* abs() */
#include <string.h>   /* memcpy */
#include <ctype.h>    /* tolower */
#include <Encoder.h>
#include "math.h"
#include "TempSensor.h"
#include "adc.h"
#include "CANBus.h"

/* =========================================================================
 * Configuration
 * ========================================================================= */

#define SUPPLY_VOLTAGE          12.0f
#define FAULT_CHECK_MS          10
#define PLOT_MS                 100
#define ENDSTOP_CHECK_MS        10
#define KICK_INTERVAL_MS        50      /* startup-from-rest kick rate; ISR handles motion */
#define GEAR_RATIO              24.0f

//#define ENCODER_UPDATE_MS       1
#define FILTER_FC_HERTZ         930.0f
//#define FILTER_FC_HERTZ        0.0f
#define Target                  25.0f      /* target position in encoder revs */

/* PID config — TIM6 is the control-loop tick. PID_DT MUST match the
 * actual TIM6 update rate set in CubeMX.
 *   1 kHz tick → PID_DT = 0.001f
 *   500 Hz    → PID_DT = 0.002f
 *   etc. */
#define PID_DT                  0.001f
#define MAX_PID_V               12.0f      /* output saturation, V — keep low for bench */

#define Kp                      56.8859823808594f      /* V per rev — error of 0.4 rev → 2V (saturated) */
#define Ki                      593.026668448812f
#define Kd                      1.03592960739312f

//#define Kp                      0.062f      /* V per rev — error of 0.4 rev → 2V (saturated) */
//#define Ki                      7.2926f
//#define Kd                      0.0f

static float Kff = 0.25761f;   /* V·s/rev — set after identification */
//static float Kff = 0.0f;   /* V·s/rev — set after identification */


#define CYCLE_OUT_POS     25.0f    	  /* rev - 4 * 25 = 100mm stroke*/
#define CYCLE_IN_POS      0.0f
#define CYCLE_VMAX        15.1375f    /* rev/s — your thermal cap */
#define CYCLE_AMAX        18.32627f    /* rev/s² */


/* ---------------- CAN command protocol ---------------- */
#define CAN_ID_GOTO             0x100   /* payload: float32 LE, target rev */
#define CAN_ID_AUTOCYCLE        0x101   /* no payload */
#define CAN_ID_STOP             0x102   /* no payload */
#define CAN_ID_HOMING           0x103   /* no payload */
#define CAN_ID_PING             0x104   /* no payload */

#define CAN_ID_STATUS_REPLY     0x200   /* MCU -> bus, status snapshot */
#define CAN_ID_ACK_REPLY        0x201   /* MCU -> bus, command ack/err */
static void CAN_DispatchCommands(void);
static void CAN_Reply(uint32_t id, const uint8_t *data, uint8_t len);


/* Default normal-operation drive direction (used only as initial value
 * for s_pidDir before the PID has run). +1 forward, -1 reverse. */
#define DIRECTION               (1)

/* Homing: which physical direction drives the carriage TOWARD the limit
 * switch. Flip the sign if your switch is mounted at the other end. */
#define DIR_TOWARD_SWITCH       (-1)
#define DIR_AWAY_FROM_SWITCH    (-(DIR_TOWARD_SWITCH))

/* Velocity-loop tuning */
#define HOMING_TARGET_RPM       7200.0f
#define HOMING_VOLTAGE_MIN      1.6f
#define HOMING_VOLTAGE_MAX      8.0f
#define HOMING_KI               0.05f   /* V per (rpm·s) — tune empirically */
#define HOMING_BACKOFF_EDGES    180      /* small backoff at end (output ~1/4 turn) */
#define HOMING_SETTLE_MS        1000    /* dwell at zero V after switch hit   */
#define HOMING_TICK_MS          2       /* state-machine + commutation period */

/* Stall watchdog */
#define HOMING_STALL_RPM        5.0f    /* below this = "not moving" */
#define HOMING_STALL_TIMEOUT_MS 2000U




#define TEMP_LIMIT_C   55.0f
#define TEMP_RESET_C   50.0f
#define TEMP_SAMPLE_INTERVAL_MS		500U

/* ── Thermal runaway guard ──────────────────────────────────────────
 * Catches a sustained linear temperature rise like the one observed
 * during the failed gearbox-stall test (slope ~1-3 °C/min over 30+ min).
 *
 * Steady-state slopes are well under 0.1 °C/min, so 0.3 °C/min gives
 * a comfortable margin against false trips. Confirming over 3 minutes
 * with a 5-minute slope window further filters out noise from sensor
 * quantization. */
#define THERMAL_SETTLE_MS              (10U * 60U * 1000U)   /* 10 min */
#define THERMAL_SLOPE_LIMIT_C_PER_MIN  0.3f
#define SLOPE_CONFIRM_MS               (3U * 60U * 1000U)    /* 3 min */
#define SLOPE_WINDOW_MS                (5U * 60U * 1000U)    /* 5 min */

#define TEMP_HISTORY_SIZE  60     /* 5 min at 1 Hz + headroom */

static float    s_tempHistory[TEMP_HISTORY_SIZE];
static uint32_t s_tempHistoryTimes[TEMP_HISTORY_SIZE];
static uint16_t s_tempHistoryIdx     = 0;
static uint16_t s_tempHistoryCount   = 0;
static uint32_t s_slopeBreachStartMs = 0;
static bool     s_thermalRunaway     = false;



static float ThermalGuard_ComputeSlope(void)
{
    if (s_tempHistoryCount < 4) return 0.0f;

    uint32_t now = HAL_GetTick();
    float    t_oldest    = 0.0f;
    uint32_t time_oldest = 0;
    bool     found       = false;

    /* Walk backward from newest, find the oldest sample within window */
    for (uint16_t i = 0; i < s_tempHistoryCount; i++) {
        uint16_t idx = (s_tempHistoryIdx + TEMP_HISTORY_SIZE - 1 - i) % TEMP_HISTORY_SIZE;
        if (now - s_tempHistoryTimes[idx] > SLOPE_WINDOW_MS) break;
        t_oldest    = s_tempHistory[idx];
        time_oldest = s_tempHistoryTimes[idx];
        found       = true;
    }

    if (!found) return 0.0f;

    uint16_t newestIdx   = (s_tempHistoryIdx + TEMP_HISTORY_SIZE - 1) % TEMP_HISTORY_SIZE;
    float    t_newest    = s_tempHistory[newestIdx];
    uint32_t time_newest = s_tempHistoryTimes[newestIdx];

    if (time_newest == time_oldest) return 0.0f;

    float dt_min = (float)(time_newest - time_oldest) / 60000.0f;
    return (t_newest - t_oldest) / dt_min;
}

static void ThermalGuard_AddSample(float tempC)
{
    s_tempHistory[s_tempHistoryIdx]      = tempC;
    s_tempHistoryTimes[s_tempHistoryIdx] = HAL_GetTick();
    s_tempHistoryIdx = (s_tempHistoryIdx + 1) % TEMP_HISTORY_SIZE;
    if (s_tempHistoryCount < TEMP_HISTORY_SIZE) s_tempHistoryCount++;
}




#define USB_CMD_BUF_SIZE        128

enum class HomingState : uint8_t {
    Idle, MoveToSwitch, Settle, Backoff, PostBackoffSettle ,Done
};

static volatile HomingState s_homingState   = HomingState::Idle;
static volatile bool        s_homingActive  = false;
static volatile bool        s_motorEnabled  = true;   /* gate for ISR commutation */
static volatile int8_t      s_homingDir     = 0;
static volatile float       s_homingVoltage = 0.0f;
static int32_t              s_backoffStartEdges = 0;
static uint32_t             s_settleDeadline    = 0;

static bool homingCompleted = false;
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

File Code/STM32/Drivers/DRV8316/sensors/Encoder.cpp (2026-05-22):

/*
 * encoder.cpp
 *
 *  Created on: 7. mai 2026
 *      Author: Benjamin
 */

#include <Encoder.h>
#include "usbd_cdc_if.h"
#include <stdio.h>

/* =========================================================================
 * Construction / init
 * ========================================================================= */

Encoder::Encoder(I2C_HandleTypeDef *hi2c, float gearRatio)
    : m_hi2c(hi2c),
      m_gearRatio(gearRatio),
      m_rotations(0),
      m_lastAngle(0),
      m_currentAngle(0),
      m_initialised(false),
      m_magnetOK(false),
      m_velRaw(0.0f),
      m_velFiltered(0.0f),
      m_velFilterFc(20.0f),       /* default: 20 Hz cutoff (smooth display) */
      m_lastPositionRev(0.0f),
      m_lastUpdateTick(0),
      m_velPrimed(false)
{
}

bool Encoder::begin()
{
    m_rotations = 0;

    uint16_t angle;
    if (readAngle(angle))
    {
        m_lastAngle    = angle;
        m_currentAngle = angle;
        m_initialised  = true;
    }
    else
    {
        m_initialised = false;
    }

    uint8_t status = readStatus();
    m_magnetOK = (status != 0xFF) && ((status & MD_BIT) != 0);

    /* Velocity state — wait for the first update() to prime */
    m_velRaw          = 0.0f;
    m_velFiltered     = 0.0f;
    m_lastPositionRev = getPositionRev();
    m_lastUpdateTick  = HAL_GetTick();
    m_velPrimed       = false;

    return m_initialised;
}

/* =========================================================================
 * Per-loop update
 * ========================================================================= */

bool Encoder::update(float dt_s)
{
    uint16_t angle;
    if (!readAngle(angle)) return false;

    /* Wrap detection — unchanged */
    if (!m_initialised) {
        m_lastAngle = angle;
        m_currentAngle = angle;
        m_initialised = true;
    } else {
        int32_t delta = (int32_t)angle - (int32_t)m_lastAngle;
        if      (delta >  WRAP_THRESHOLD) m_rotations--;
        else if (delta < -WRAP_THRESHOLD) m_rotations++;
        m_lastAngle = angle;
        m_currentAngle = angle;
    }

    /* Velocity with caller-supplied dt — no HAL_GetTick() at all */
    float pos_rev = getPositionRev();

    if (!m_velPrimed) {
        m_lastPositionRev = pos_rev;
        m_velRaw = 0.0f;
        m_velFiltered = 0.0f;
        m_velPrimed = true;
    } else if (dt_s > 0.0f) {
        m_velRaw = (pos_rev - m_lastPositionRev) / dt_s;

        float omega = 6.28318530718f * m_velFilterFc;
        float a = (omega * dt_s) / (1.0f + omega * dt_s);
        if (a < 0.0f) a = 0.0f;
        if (a > 1.0f) a = 1.0f;

        m_velFiltered = (1.0f - a) * m_velFiltered + a * m_velRaw;
        m_lastPositionRev = pos_rev;
    }
    return true;
}


/* Keep the old one as a thin wrapper for non-time-critical callers */
bool Encoder::update()
{
    uint32_t now = HAL_GetTick();
    float dt_s = (m_velPrimed && now > m_lastUpdateTick)
                   ? (float)(now - m_lastUpdateTick) * 0.001f
                   : 0.001f;
    m_lastUpdateTick = now;
    return update(dt_s);
}

/* =========================================================================
 * Reset
 * ========================================================================= */

void Encoder::resetCount()
{
    m_rotations = 0;

    /* Re-baseline so the next update() doesn't see a phantom wrap */
    uint16_t angle;
    if (readAngle(angle))
    {
        m_lastAngle    = angle;
        m_currentAngle = angle;
        m_initialised  = true;
    }

    /* Reset velocity state too — otherwise the position jump from
     * resetCount() would produce a huge velocity spike. */
    m_velRaw          = 0.0f;
    m_velFiltered     = 0.0f;
    m_lastPositionRev = getPositionRev();
    m_lastUpdateTick  = HAL_GetTick();
    m_velPrimed       = true;     /* baseline is now valid */
}

/* =========================================================================
 * Velocity filter configuration
 * ========================================================================= */

void Encoder::setVelocityFilterHz(float fc_hz)
{
    if (fc_hz < 0.1f)  fc_hz = 0.1f;     /* avoid division-by-zero issues */
    m_velFilterFc = fc_hz;
}

/* =========================================================================
 * Low-level I2C
 * ========================================================================= */

bool Encoder::readAngle(uint16_t &out)
{
    uint8_t reg    = REG_RAW_ANGLE_H;
    uint8_t buf[2] = {0, 0};

    if (HAL_I2C_Master_Transmit(m_hi2c, I2C_ADDR, &reg, 1, I2C_TIMEOUT_MS) != HAL_OK)
        return false;
    if (HAL_I2C_Master_Receive(m_hi2c, I2C_ADDR, buf, 2, I2C_TIMEOUT_MS) != HAL_OK)
        return false;

    out = ((uint16_t)(buf[0] & 0x0F) << 8) | buf[1];
    return true;
}

uint8_t Encoder::readStatus()
{
    uint8_t reg = REG_STATUS;
    uint8_t val = 0xFF;

    if (HAL_I2C_Master_Transmit(m_hi2c, I2C_ADDR, &reg, 1, I2C_TIMEOUT_MS) != HAL_OK)
        return 0xFF;
    if (HAL_I2C_Master_Receive(m_hi2c, I2C_ADDR, &val, 1, I2C_TIMEOUT_MS) != HAL_OK)
        return 0xFF;

    return val;
}

/* =========================================================================
 * Backward-compatible C diagnostic
 * ========================================================================= */

extern "C" void TESTENCODER_Update(I2C_HandleTypeDef *hi2c)
{
    /* Static instance so repeated calls accumulate rotation count.
     * Default gear ratio 1.0f — change here if you want gearbox-aware
     * output from the diagnostic. */
    static Encoder s_diagEnc(hi2c, 1.0f);
    static bool    s_started = false;

    if (!s_started)
    {
        s_diagEnc.begin();
        s_started = true;
    }

    bool ok = s_diagEnc.update();

    char msg[80];
    int  len;

    if (!ok)
    {
        len = snprintf(msg, sizeof(msg), "I2C ERROR - bus may be locked up\r\n");
    }
    else
    {
        float deg = s_diagEnc.getRawAngle() * (360.0f / 4096.0f);
        len = snprintf(msg, sizeof(msg),
                       "raw=%4u deg=%7.2f rot=%ld magOK=%c\r\n",
                       s_diagEnc.getRawAngle(),
                       deg,
                       (long)s_diagEnc.getRotations(),
                       s_diagEnc.isMagnetOK() ? '1' : '0');
    }

    for (int i = 0; i < 3; i++)
    {
        if (CDC_Transmit_FS((uint8_t *)msg, (uint16_t)len) == USBD_OK)
            break;
        HAL_Delay(1);
    }
}

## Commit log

2026-05-22 Initial import of bachelor project files
    [Actuator_assembly.SLDASM, Actuator_assembly.SLDDRW, Actuator_assembly_fully_extended.SLDDRW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]
2026-05-22 Initial commit of README for Closed-Loop Linear Actuator
    Added detailed project description, features, hardware components, and instructions for building and flashing the actuator.

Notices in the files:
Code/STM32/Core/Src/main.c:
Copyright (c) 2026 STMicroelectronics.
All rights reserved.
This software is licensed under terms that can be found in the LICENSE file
